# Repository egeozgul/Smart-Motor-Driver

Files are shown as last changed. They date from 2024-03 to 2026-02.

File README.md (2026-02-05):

# Servo Motor Feedback Controller

<p align="center">
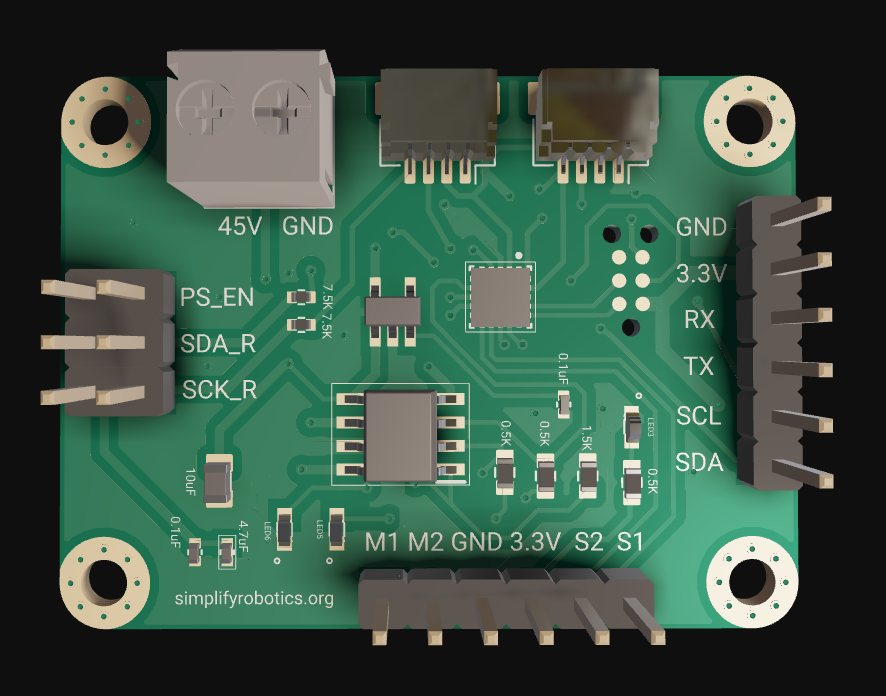
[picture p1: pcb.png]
Encoder Motor Driver - Front View
  
</p>

<!-- https://github.com/user-attachments/assets/069eb083-97e3-404b-9e9d-383a1cb0ce94 -->

## PCB assembly video
Watch the assembly video (https://youtu.be/LhhGqf6qH90)

The **Smart Encoder Motor Driver** is designed to control DC motors with magnetic or optical encoders. It features a built-in feedback controller and H-bridge, allowing precise motor power adjustment based on commands from a master device. Powered by the **STM32C0 microcontroller** and equipped with a **PID feedback system**, this driver ensures reliable and efficient motor control.

## Key Features
- **Built-in Feedback Controller**: High-frequency PID control for precise motor operation.
- **Trapezoidal Trajectory Planner**: Ensures smooth acceleration and deceleration by generating motion profiles for precise movement control.
- **Digital Communication**: Supports ASCII commands for setting motor target positions, tuning PID coefficients, monitoring torque feedback, and more.
- **Voltage Range**: 5V to 45V.
- **Current Capacity**: Up to 4.1 amps.
- **Communication**: Supports I2C and UART protocols.
- **Expandable Design**: Qwiic connectors allow daisy-chaining of up to 256 units on a single I2C port.

## Trapezoidal Trajectory Planner
The driver includes an **embedded trapezoidal trajectory generator**, which ensures smooth motor motion by controlling acceleration and deceleration. This feature prevents sudden jerks, reduces mechanical stress, and improves overall system stability.

### Key Benefits
- Smooth position transitions with controlled acceleration and deceleration.
- Prevents overshooting and oscillations.
- Customizable speed, acceleration, and deceleration limits.

### Motion Profile

The controller automatically computes the trajectory based on the target position, velocity, and acceleration constraints.
A custom web-based UART plotter is used for live plotting of motor motion parameters. 

The plots below display: 
1. Position
2. Velocity
3. Current drawn by the motor

scr

## Custom Live Plotter
A custom live plotter is built for monitoring the motor speed, acceleration, and current draw.  
Check out the [Live UART Plotter](https://egeozgul.github.io/live-uart/) to visualize real-time data from your motor driver.  
It supports plotting an unlimited number of variables with customizable styling.

## Final PCB Design Iteration
IMG-20250525-WA0009

447361824-5bac32cf-38b6-4dda-9f8f-5560bae4baff

The **PID feedback control system** ensures precise and stable motor control, making it suitable for robotics, automation, and other applications requiring high precision.

## Connectivity and Expansion
The motor driver is designed for scalability, using **Qwiic connectors** for easy daisy-chaining. This allows control of a large number of motors, making it ideal for projects requiring extensive motor coordination.

## License
This project is open-source under the MIT License. Feel free to modify and distribute it as needed!

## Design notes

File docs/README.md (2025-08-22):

# Smart Motor Driver Documentation

## Overview
The Smart Motor Driver is a high-precision motor control system based on STM32C0 microcontroller, featuring PID control, trapezoidal motion profiles, and multiple communication interfaces.

## Documentation Structure

### [User Guide](USER_GUIDE.md)
- Getting started guide
- Command interface tutorial
- Usage examples
- Troubleshooting guide
- No C code, focused on usage

### [Technical Reference](REFERENCE.md)
- Hardware specifications
- ASCII command protocol
- Motion control commands
- PID tuning parameters
- Motion profile settings
- Monitoring commands
- System commands

### [Source Code Documentation](SOURCECODE.md)
- Core components implementation
- Motion profile generation
- Communication interfaces
- Hardware interfaces
- Data structures
- C code explanations

## Quick Links

### Common Tasks
- [Basic Motor Control](USER_GUIDE.md#basic-motor-control)
- [PID Tuning Guide](USER_GUIDE.md#pid-tuning)
- [Command Reference](REFERENCE.md#ascii-command-protocol)
- [Implementation Details](SOURCECODE.md#core-components)

### Key Features
- Position and speed control
- Trapezoidal motion profiles
- PID control with anti-windup
- Current monitoring
- UART and I2C interfaces
- 64-bit position tracking

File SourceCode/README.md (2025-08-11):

# STM32 Motor Controller Firmware

## 1. Introduction

This document provides a comprehensive overview of the firmware for a sophisticated motor control system based on an STM32 microcontroller. The system is designed to offer precise control over a DC motor, featuring position and speed control, a command-line interface for configuration and monitoring, and support for both UART and I2C communication protocols.

The firmware is built upon the STM32 HAL library and integrates several peripherals, including timers for PWM signal generation and encoder reading, an ADC for current sensing, and DMA for efficient data handling.

### Key Features:

* **Dual Communication Interface:** Control and monitor the motor via both UART and I2C.
* **Advanced Motion Control:**
    * **PID Control:** A Proportional-Integral-Derivative (PID) controller for precise position holding.
    * **Trapezoidal Profiling:** Smooth acceleration and deceleration for point-to-point movements.
* **Real-time Monitoring:** Stream motor position, speed (in ticks per second), and current consumption.
* **Command-Line Interface (CLI):** An intuitive text-based command system to configure parameters and control the motor.
* **Quadrature Encoder Support:** High-resolution position feedback from the motor.
* **Current Sensing:** Onboard ADC for monitoring motor current draw.
* **DMA-driven Communication:** Efficient data transfer for both UART and I2C, minimizing CPU overhead.

## 2. Hardware Setup

The firmware is configured to work with a specific set of STM32 peripherals. The primary components are:

* **`TIM1`:** For PWM generation to drive the H-bridge.
* **`TIM3`:** For reading the quadrature encoder.
* **`ADC1`:** For current sensing.
* **`USART2`:** For UART communication (CLI).
* **`I2C1`:** For I2C slave communication.
* **`DMA`:** For handling `USART2` and `I2C1` data transfers.

## 3. Software Architecture

The firmware's architecture is event-driven and organized around a main processing loop. It initializes all peripherals, then enters an infinite loop to process incoming commands from UART or I2C, execute motor control logic (PID, Trapezoidal, etc.), and handle data logging. Interrupts are used for encoder counting and I2C communication.

## 4. Communication Protocol & API

The motor controller is operated by sending text-based commands terminated by a newline character (`\n`) over UART or I2C.

### General Commands

| Command | Argument | Description |
| :--- | :--- | :--- |
| `SETSPD` | `speed` (0-100) | Sets the motor speed (Note: This function appears to be a placeholder). |
| `SETPOS` | `position` (integer) | Sets the target position for the PID controller and enters `MOTOR_PID` mode. |
| `MOVETO` | `position` (integer) | Moves the motor to a target position using a trapezoidal profile. Enters `MOTOR_TRAPEZOID` mode. |
| `FLOAT` | None | Disengages the motor, allowing it to spin freely. |
| `BRAKE` | None | Brakes the motor by shorting the terminals through the H-bridge. |
| `GETSPD` | None | Returns the current speed of the motor in ticks per second. |
| `GETPOS` | None | Returns the current 64-bit encoder position. |
| `GET_ADC` | None | Returns the current motor current in milliamps (mA). |
| `STATUS` | None | Returns the current drive mode of the motor. |
| `RESET` | None | Resets the microcontroller. |

### Configuration Commands

| Command | Argument | Description |
| :--- | :--- | :--- |
| `SET_P` | `value` (float) | Sets the Proportional (Kp) gain for the PID controller. |
| `SET_I` | `value` (float) | Sets the Integral (Ki) gain for the PID controller. |
| `SET_D` | `value` (float) | Sets the Derivative (Kd) gain for the PID controller. |
| `GET_PID` | None | Returns the current Kp, Ki, and Kd values. |
| `SETMAX_VEL` | `value` (float) | Sets the maximum velocity for trapezoidal moves. |
| `SETMAX_ACC` | `value` (float) | Sets the maximum acceleration for trapezoidal moves. |
| `GETMAX_VEL` | None | Returns the current maximum velocity setting. |
| `GETMAX_ACC` | None | Returns the current maximum acceleration setting. |
| `LOG` | `period` (ms) | Starts streaming `pos`, `amps`, and `tps` data every `period` milliseconds. Set to 0 to disable. |
| `CONFIRM` | `0` or `1` | Disables (0) or enables (1) confirmation messages for set commands. |

### Example Usage (UART)

1.  **Set PID gains:**
    ```
    SET_P 0.005
    SET_I 0.0001
    SET_D 0.01
    ```

2.  **Move to position 50000:**
    ```
    MOVETO 50000
    ```

3.  **Start logging data every 100ms:**
    ```
    LOG 100
    ```

    *Output:*
    ```
    pos 12345,amps 150.5,tps 5000
    pos 17345,amps 152.3,tps 5000
    ...
    ```

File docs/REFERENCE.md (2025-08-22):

# Smart Motor Driver - Technical Reference

## Technical Specifications

### Hardware Configuration
* **Microcontroller**: STM32C0 series
* **PWM Frequency**: Timer1 based
* **Encoder Resolution**: Quadrature encoding (4x)
* **ADC Resolution**: 12-bit (0-4095 steps)
* **Communication**:
  - UART: DMA-based, configurable baud rate
  - I2C: Slave mode, 7-bit addressing

### Control Parameters
* **Position Range**: 64-bit signed (-2^63 to 2^63-1)
* **PID Update Rate**: ~1kHz
* **Current Sensing**:
  - Resolution: 0.8mA (3.3V/4095/1.5kΩ)
  - Range: 0-2.2mA

## ASCII Command Protocol

### Motion Control Commands

#### SETPOS
- **Format**: `SETPOS <position>`
- **Parameters**: 64-bit signed integer
- **Response**: "Pos <value>"
- **Description**: Sets target position in PID mode
- **Example**: `SETPOS 1000`
- **Behavior**:
  - Immediate position command
  - Uses current PID settings
  - No acceleration limiting

#### MOVETO
- **Format**: `MOVETO <position>`
- **Parameters**: 64-bit signed integer
- **Response**: "Moving to <value>"
- **Description**: Moves to position using trapezoidal profile
- **Example**: `MOVETO 5000`
- **Profile Types**:
  1. Triangular (short moves)
     - When distance < 2 * acceleration_distance
     - No constant velocity phase
  2. Trapezoidal (long moves)
     - Acceleration phase
     - Constant velocity phase
     - Deceleration phase
- **Timing**:
  - T_accel = V_max / A_max
  - T_const = (distance - 2*D_accel) / V_max

#### SETSPD
- **Format**: `SETSPD <speed>`
- **Parameters**: 0-100 (percentage)
- **Response**: "Speed <value>%"
- **Description**: Sets motor speed
- **Example**: `SETSPD 50`

### State Control Commands

#### FLOAT
- **Format**: `FLOAT`
- **Parameters**: None
- **Response**: None
- **Description**: Disables motor power
- **Effects**:
  - Sets both PWM channels to 0
  - Disables H-bridge outputs
  - Allows free shaft rotation
  - Minimal power consumption
- **Use Cases**:
  - Manual positioning
  - Emergency stop
  - Power saving mode
  - System initialization

#### BRAKE
- **Format**: `BRAKE`
- **Parameters**: None
- **Response**: None
- **Description**: Engages motor brake
- **Effects**:
  - Sets both PWM channels to 50%
  - Creates active braking torque
  - Holds position against external forces
  - Higher power consumption
- **Use Cases**:
  - Emergency stop
  - Position holding
  - Load testing
  - Safety lockout

### PID Control Commands

#### SET_P/SET_I/SET_D
- **Format**: `SET_P <value>`, `SET_I <value>`, `SET_D <value>`
- **Parameters**: Float value (scientific notation supported)
- **Response**: Confirms new value
- **Description**: Sets PID parameters
- **Examples**:
  ```
  SET_P 0.001   # Moderate response
  SET_P 0.0001  # Slower, smoother response
  SET_I 0.0001  # Light integral action
  SET_D 0.00001 # Light damping
  ```
- **Parameter Effects**:
  - P (Proportional):
    - Range: 0.0001 to 0.01
    - Controls position error response
    - Higher: Faster but may oscillate
    - Lower: Smoother but slower
  - I (Integral):
    - Range: 0.0 to 0.001
    - Eliminates steady-state error
    - Anti-windup limited to ±100
  - D (Derivative):
    - Range: 0.0 to 0.0001
    - Provides damping
    - Reduces overshoot

#### GET_PID
- **Format**: `GET_PID`
- **Response**: "Kp <p>,Ki <i>,Kd <d>"
- **Description**: Returns current PID values
- **Output Format**: Scientific notation, 7 decimal places
- **Default Values**:
  ```
  Kp = 0.0001
  Ki = 0.0
  Kd = 0.0
  ```

### Motion Profile Commands

#### SETMAX_VEL
- **Format**: `SETMAX_VEL <velocity>`
- **Parameters**: Float velocity value
- **Description**: Sets maximum velocity for profiles
- **Default**: 20.0

#### SETMAX_ACC
- **Format**: `SETMAX_ACC <acceleration>`
- **Parameters**: Float acceleration value (0.01-1.0)
- **Description**: Sets maximum acceleration for profiles
- **Default**: 0.05
- **Effects**:
  - Limits acceleration in trapezoidal profiles
  - Affects move time calculation
  - Influences jerk and smoothness
- **Calculation**:
  ```
  D_accel = (V_max * V_max) / (2 * A_max)
  T_accel = V_max / A_max
  ```

### Monitoring Commands

#### GETPOS
- **Format**: `GETPOS`
- **Response**: `Pos <value>`
- **Description**: Returns encoder position
- **Features**:
  - 64-bit signed integer
  - No overflow issues
  - Quadrature decoded (4x resolution)
  - Updates at ~1kHz

#### GETSPD
- **Format**: `GETSPD`
- **Response**: `Spd <value>`
- **Description**: Returns motor speed
- **Features**:
  - Units: counts/second
  - Filtered for noise reduction
  - Sign indicates direction
  - Updates at ~1kHz

#### GET_ADC
- **Format**: `GET_ADC`
- **Response**: `ADC <raw>,<mA>`
- **Description**: Returns current sensing data
- **Features**:
  - Raw ADC value (0-4095)
  - Calculated current in mA
  - 12-bit resolution
  - ~0.8mA per step

#### STATUS
- **Format**: `STATUS`
- **Response**: Current mode (FLOAT/BRAKE/PID/TRAPEZOID)
- **Description**: Returns drive state

### System Commands

#### LOG
- **Format**: `LOG <period>`
- **Parameters**: Integer period value
- **Description**: Sets data logging period

#### CONFIRM
- **Format**: `CONFIRM <0/1>`
- **Parameters**: 0 (off) or 1 (on)
- **Description**: Enables/disables command confirmations

## Features Reference

### Motion Profiles
- Trapezoidal velocity profile
- Automatic profile selection (triangular/trapezoidal)
- Configurable velocity and acceleration limits
- Real-time trajectory computation

### Position Control
- 64-bit position counter
- PID control with anti-windup
- Configurable gains
- Encoder-based feedback

### Current Monitoring
- ADC-based current sensing
- 12-bit resolution
- 1.5kΩ sense resistor
- Real-time measurement

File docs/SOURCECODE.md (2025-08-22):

# Smart Motor Driver - Source Code Documentation

## Core Components

### Motor Control System

#### PWM Control
* **Function**: `UpdatePWMDutyCycle(uint32_t channel, uint32_t value)`
* **Purpose**: Controls motor speed and direction using PWM channels
* **Implementation**:
  ```c
  // Configure PWM channel
  sConfigOC.OCMode = TIM_OCMODE_PWM1;
  sConfigOC.Pulse = value;          // PWM duty cycle
  sConfigOC.OCPolarity = TIM_OCPOLARITY_HIGH;
  // Start PWM output
  HAL_TIM_PWM_Start_optimized(&htim1, channel);
  ```
* **Usage**:
  - Channel 3: Forward direction
  - Channel 4: Reverse direction
  - Value range: 0 to Timer Period

#### Encoder Interface
* **Function**: `get_full_encoder_count()`
* **Purpose**: Reads absolute motor position
* **Implementation**:
  ```c
  int64_t count = full_encoder_count + 
                  __HAL_TIM_GET_COUNTER(&htim3) - 65536;
  ```
* **Features**:
  - 64-bit position counter
  - Overflow handling
  - High-resolution tracking

#### PID Controller
* **Function**: `update_PID()`
* **Purpose**: Closed-loop position control
* **Key Variables**:
  ```c
  float Kp = 0.0001;  // Proportional gain
  float Ki = 0.0;     // Integral gain
  float Kd = 0.0;     // Derivative gain
  #define INTEGRAL_MAX 100  // Anti-windup limit
  ```
* **Algorithm**:
  1. Position error calculation
  2. Integral accumulation with anti-windup
  3. Derivative computation
  4. PWM output generation

### Motion Profiles

#### Trapezoidal Profile Generator
* **Initialization**: `initializeTrajectory(int64_t start, int64_t target)`
* **Implementation**:
  ```c
  // Calculate acceleration distance
  D_accel = (V_max * V_max) / (2.0f * A_max);
  
  if (totalDistance < 2 * D_accel) {
      // Triangular profile
      D_accel = totalDistance / 2;
      T_accel = custom_sqrtf(2.0f * D_accel / A_max);
      T_const = 0.0f;
  } else {
      // Trapezoidal profile
      T_accel = V_max / A_max;
      T_const = (totalDistance - 2 * D_accel) / V_max;
  }
  ```
* **Profile Parameters**:
  - `V_max`: Maximum velocity (default: 20.0)
  - `A_max`: Maximum acceleration (default: 0.05)
  - `T_accel`: Acceleration/deceleration time
  - `T_const`: Constant velocity time

#### Profile Update
* **Function**: `updateTrajectory(float dt)`
* **Phases**:
  1. Acceleration: Quadratic position increase
  2. Constant velocity: Linear position change
  3. Deceleration: Inverted quadratic
* **Implementation**:
  ```c
  if (currentTime <= T_accel) {
      // Acceleration phase
      setpointPos = startPos + direction * 
          (int64_t)((A_max * currentTime * currentTime) / 2.0f);
  } else if (currentTime <= T_accel + T_const) {
      // Constant velocity phase
      setpointPos = startPos + direction * 
          (int64_t)(V_max * (currentTime - T_accel));
  }
  ```

### Communication Interfaces

#### UART Interface
* **Configuration**:
  ```c
  #define DMA_BUFFER_SIZE 2048
  uint8_t rxBuffer[DMA_BUFFER_SIZE];
  ```
* **Features**:
  - DMA circular buffer for efficient reception
  - Non-blocking command processing
  - Automatic buffer wraparound

* **Command Processing**:
  ```c
  void ProcessCommand(uint8_t *buffer, int bufferSize, 
                     DMA_HandleTypeDef *hdmarx, 
                     uint16_t *lastParsedIndex)
  ```

#### I2C Interface
* **Buffer Management**:
  ```c
  #define I2C_BUFFER_SIZE 64
  uint8_t i2cTxBuffer[I2C_BUFFER_SIZE];
  ```
* **Features**:
  - Slave mode with 7-bit addressing
  - Interrupt-driven data transmission
  - Cyclic buffer with overflow protection

* **Data Handling**:
  ```c
  void I2C_IRQHandler_User(I2C_HandleTypeDef *hi2c)
  ```

### Command Processing

#### Command Parser
* **Function**: `handleCommand(uint8_t *buffer, int bufferSize, uint16_t commandIndex)`
* **Buffer Processing**:
  ```c
  #define MAX_COMMAND_LENGTH 25
  char command[MAX_COMMAND_LENGTH];
  // Extract command from circular buffer
  for (int i = 0; i < MAX_COMMAND_LENGTH; i++) {
      int buffer_i = (commandIndex - i);
      if (buffer_i < 0)
          buffer_i = bufferSize - buffer_i;
      command[MAX_COMMAND_LENGTH - i - 1] = buffer[buffer_i];
  }
  ```

#### Command Parser Components
* **String Functions**:
  ```c
  int strcmp_embedded(const char *str1, const char *str2)
  int atoi_embedded(const char *str)
  ```
* **Command Format**: `COMMAND VALUE\n`
* **Error Handling**:
  - Buffer overflow protection
  - Invalid command detection
  - Value range validation

### Hardware Interfaces

#### ADC Interface
* **Function**: `readADCValue()`
* **Implementation**:
  ```c
  uint32_t readADCValue() {
      HAL_ADC_Start(&hadc1);
      if (HAL_ADC_PollForConversion(&hadc1, 100) == HAL_OK) {
          uint32_t adcValue = HAL_ADC_GetValue(&hadc1);
      }
      HAL_ADC_Stop(&hadc1);
      return adcValue;
  }
  ```
* **Current Calculation**:
  ```c
  float Vipropi = ((float)adc_value * (3.3f/4095.0f));
  float Ipropi = Vipropi/1.5f;  // Current in mA
  ```
* **Features**:
  - 12-bit resolution (0-4095)
  - Voltage reference: 3.3V
  - Current sense resistor: 1.5kΩ
  - Polling mode with timeout

#### Timer Configuration
* **PWM Timer (TIM1)**:
  - Channels 3,4: H-bridge control
  - Complementary outputs
  - Dead-time insertion

* **Encoder Timer (TIM3)**:
  - 16-bit counter
  - Quadrature decoding
  - Overflow handling for 64-bit position

### Key Data Structures
* **Cyclic Buffer**:
  ```c
  uint8_t i2cTxBuffer[I2C_BUFFER_SIZE];
  int head;  // Write position
  int tail;  // Read position
  int is_full;
  ```

### Important Constants
```c
#define DMA_BUFFER_SIZE 2048
#define I2C_BUFFER_SIZE 64
#define INTEGRAL_MAX 100
#define MAX_COMMAND_LENGTH 25
```

### Drive Modes
```c
#define MOTOR_FLOAT     0  // No power to motor
#define MOTOR_BRAKE     1  // Active braking
#define MOTOR_PID       2  // Position control
#define MOTOR_TRAPEZOID 3  // Profile motion
```

## Implementation Details

### PID Control Loop
```c
void update_PID() {
    int64_t currentPos = get_full_encoder_count();
    int64_t error = setpointPos - currentPos;
    integral += error;
    integral = constrain(integral, -INTEGRAL_MAX, INTEGRAL_MAX);
    int64_t derivative = error - previousError;
    double output = (Kp * error + Ki * integral + Kd * derivative)/10;
    // Apply output to PWM channels
}
```

### Trapezoidal Profile Generation
```c
void initializeTrajectory(int64_t start, int64_t target) {
    totalDistance = abs(target - start);
    D_accel = (V_max * V_max) / (2.0f * A_max);
    
    if (totalDistance < 2 * D_accel) {
        // Triangular profile
        D_accel = totalDistance / 2;
        T_accel = sqrt(2.0f * D_accel / A_max);
        T_const = 0;
    } else {
        // Trapezoidal profile
        T_accel = V_max / A_max;
        T_const = (totalDistance - 2 * D_accel) / V_max;
    }
}
```

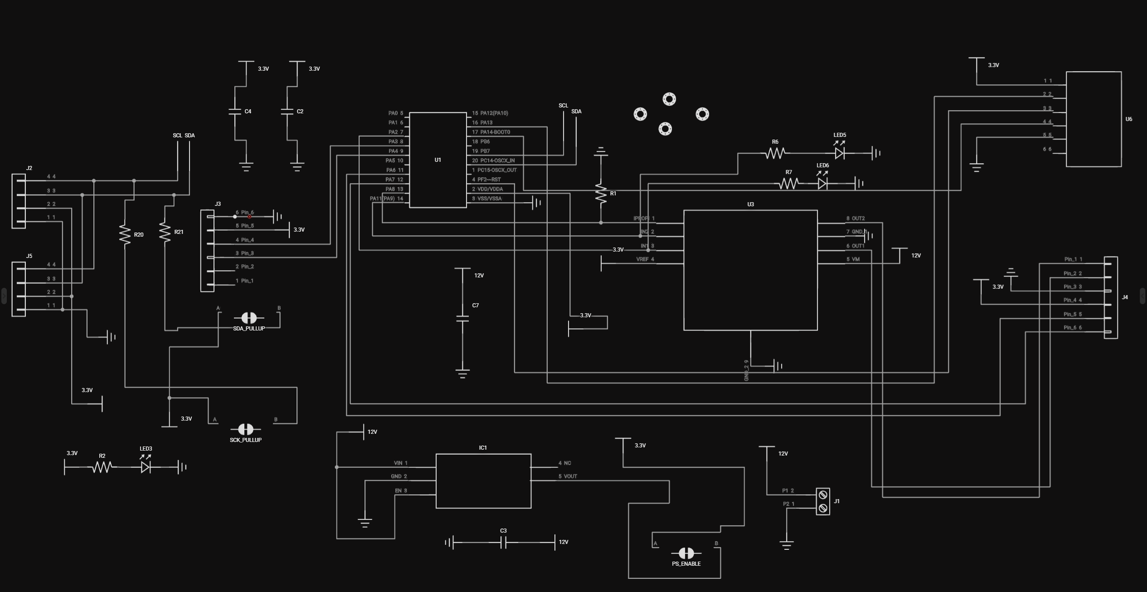
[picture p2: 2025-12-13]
schematic.png

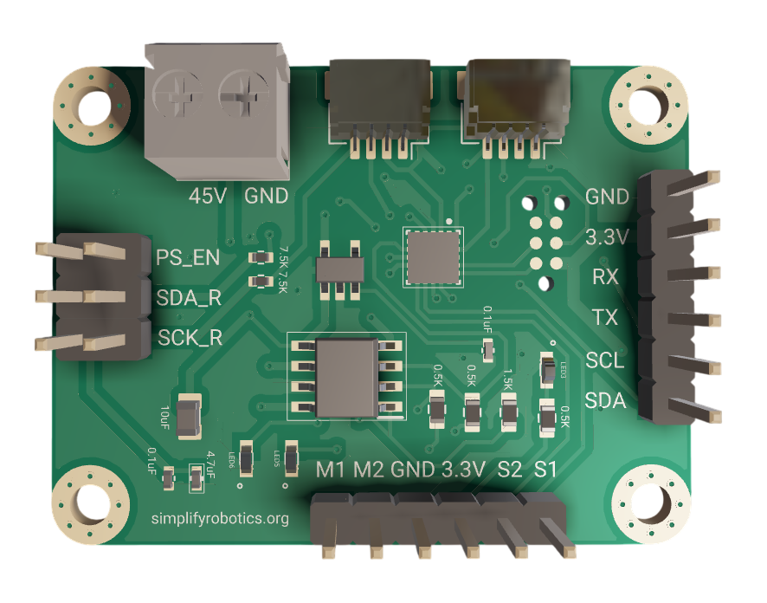
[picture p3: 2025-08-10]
pcb_transparent.png

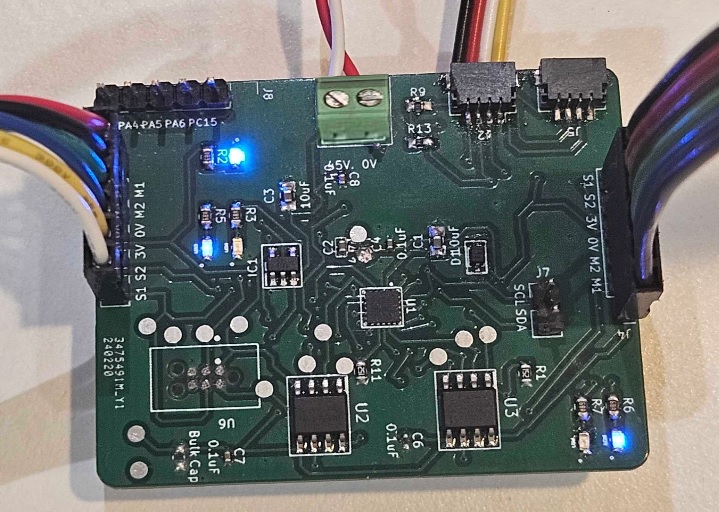
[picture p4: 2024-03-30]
imageC.jpg

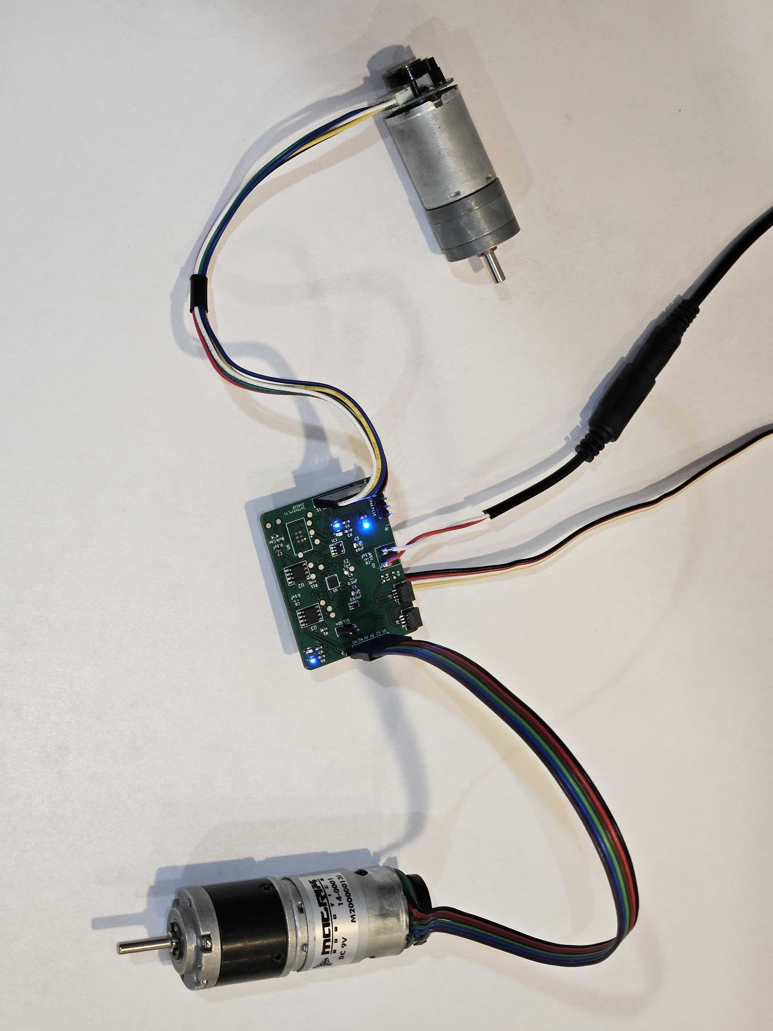
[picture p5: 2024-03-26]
imageA.jpg

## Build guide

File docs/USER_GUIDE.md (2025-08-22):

# Smart Motor Driver - User Guide

## Overview
The Smart Motor Driver is a sophisticated motor control system built on STM32 microcontroller, providing precise control over DC motor position, speed, and movement profiles. This guide explains how to use the system through its ASCII command interface over UART or I2C.

## Features
* High-precision position control with configurable PID parameters
* Variable speed control with PWM (0-100%)
* Advanced trapezoidal motion profiles for smooth movement
* Real-time current monitoring with mA resolution
* Multiple operation modes:
  - Float: No power to motor (free movement)
  - Brake: Active braking with 50% PWM
  - PID: Closed-loop position control
  - Trapezoid: Smooth motion with acceleration control

## Command Interface

### Basic Commands

#### Motor State Control
* `FLOAT` - Sets motor to floating state
  - Disables both PWM channels
  - Allows free movement of motor shaft
  - Useful for manual positioning or power saving

* `BRAKE` - Engages motor brake
  - Sets both PWM channels to 50% duty cycle
  - Creates active braking effect
  - Holds position against external forces

#### Status Commands
* `GETPOS` - Returns current motor position
  - Reports absolute encoder position
  - 64-bit counter value
  - Maintains position through power cycles

* `GETSPD` - Returns current motor speed
  - Reports real-time velocity
  - Calculated from encoder counts
  - Updates continuously

* `STATUS` - Shows current operating mode
  - Reports: FLOAT/BRAKE/PID/TRAPEZOID
  - Indicates active control method
  - Useful for debugging

### Motion Control

#### Position Commands
* `SETPOS <value>` - Set target position (PID mode)
  - Immediate position command
  - Uses PID control for positioning
  - Value is in encoder counts
  - Example: `SETPOS 1000`

* `MOVETO <value>` - Move to position using trapezoidal profile
  - Smooth motion with controlled acceleration
  - Automatically calculates optimal profile
  - Prevents mechanical stress
  - Example: `MOVETO 5000`

#### Speed Control
* `SETSPD <0-100>` - Set motor speed
  - Direct PWM duty cycle control
  - Range: 0% (stop) to 100% (full speed)
  - Linear speed control
  - Example: `SETSPD 75`

### PID Control

#### Tuning Commands
* `SET_P <value>` - Set proportional gain
  - Controls position error response
  - Higher values: faster response
  - Lower values: smoother motion
  - Example: `SET_P 0.001`

* `SET_I <value>` - Set integral gain
  - Eliminates steady-state error
  - Higher values: better position holding
  - Lower values: less oscillation
  - Example: `SET_I 0.0001`

* `SET_D <value>` - Set derivative gain
  - Dampens oscillations
  - Higher values: more damping
  - Lower values: faster response
  - Example: `SET_D 0.00001`

* `GET_PID` - Display current PID values
  - Shows all three parameters
  - Format: "Kp <p>,Ki <i>,Kd <d>"
  - Useful for tuning verification

### Motion Profile Settings

#### Velocity and Acceleration Control
* `SETMAX_VEL <value>` - Set maximum velocity
  - Limits peak velocity in trapezoidal profile
  - Units: encoder counts per second
  - Default: 20.0
  - Example: `SETMAX_VEL 15.5`

* `SETMAX_ACC <value>` - Set maximum acceleration
  - Controls acceleration/deceleration rate
  - Units: encoder counts per second²
  - Default: 0.05
  - Example: `SETMAX_ACC 0.03`

#### Profile Monitoring
* `GETMAX_VEL` - Display maximum velocity
  - Shows current velocity limit
  - Used for profile verification

* `GETMAX_ACC` - Display maximum acceleration
  - Shows current acceleration limit
  - Used for profile verification

### Monitoring and Diagnostics

#### Current Sensing
* `GET_ADC` - Read current sensor
  - Returns current in milliamps
  - High-precision ADC measurement
  - Resolution: 12-bit (4096 steps)
  - Range: 0 to (3.3V/1.5kΩ)

#### Data Logging
* `LOG <period>` - Set logging period
  - Sets update frequency for data output
  - Period in milliseconds
  - Example: `LOG 100` (10Hz update rate)

#### System Feedback
* `CONFIRM <0/1>` - Enable/disable command confirmations
  - 1: Enable command acknowledgments
  - 0: Disable command acknowledgments
  - Useful for debugging
  - Example: `CONFIRM 1`

## Usage Examples

1. Basic Position Control:
   ```
   SETPOS 1000    # Move to position 1000
   GETPOS         # Check current position
   ```

2. Smooth Motion Profile:
   ```
   SETMAX_VEL 20  # Set max velocity
   SETMAX_ACC 0.5 # Set max acceleration
   MOVETO 5000    # Move to position with trapezoidal profile
   ```

3. PID Tuning:
   ```
   SET_P 0.001    # Set proportional gain
   SET_I 0.0001   # Set integral gain
   SET_D 0.00001  # Set derivative gain
   GET_PID        # Verify settings
   ```

## Safety Features
* Current monitoring through ADC
* Software limits on velocity and acceleration
* Emergency stop through BRAKE command
* Motor float mode for manual positioning

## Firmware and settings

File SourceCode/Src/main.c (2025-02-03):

/*USER CODE BEGIN Header */
/**
 ******************************************************************************
 *@file           : main.c
 *@brief          : Main program body
 ******************************************************************************
 *@attention
 *
 *Copyright (c) 2024 STMicroelectronics.
 *All rights reserved.
 *
 *This software is licensed under terms that can be found in the LICENSE file
 *in the root directory of this software component.
 *If no LICENSE file comes with this software, it is provided AS-IS.
 *
 ******************************************************************************
 */

/*USER CODE END Header */
/*Includes ------------------------------------------------------------------*/
#include "main.h"
#include "helper.h"
//#include <stdarg.h>
//#include <stdio.h>
//#include <stdio.h>
//#include <string.h>
//#include <ctype.h>


//#include "stm32c0xx_ll_dma.h"
//#include "stm32c0xx_hal.h"
//#include "stm32c0xx_hal_uart.h"
//#include "stm32c0xx_hal_dma.h"

/*Private includes ----------------------------------------------------------*/
/*USER CODE BEGIN Includes */

/*USER CODE END Includes */

/*Private typedef -----------------------------------------------------------*/
/*USER CODE BEGIN PTD */

/*USER CODE END PTD */

/*Private define ------------------------------------------------------------*/
/*USER CODE BEGIN PD */

/*USER CODE END PD */

/*Private macro -------------------------------------------------------------*/
/*USER CODE BEGIN PM */

/*USER CODE END PM */

/*Private variables ---------------------------------------------------------*/
ADC_HandleTypeDef hadc1;
DMA_HandleTypeDef hdma_i2c1_rx;

I2C_HandleTypeDef hi2c1;

TIM_HandleTypeDef htim1;
TIM_HandleTypeDef htim3;

UART_HandleTypeDef huart2;
DMA_HandleTypeDef hdma_usart2_rx;
DMA_HandleTypeDef hdma_usart2_tx;

/*USER CODE BEGIN PV */
int computeEncoderCounterPeriod();

/*USER CODE END PV */

/*Private function prototypes -----------------------------------------------*/
void SystemClock_Config(void);
static void MX_GPIO_Init(void);
static void MX_DMA_Init(void);
static void MX_USART2_UART_Init(void);
static void MX_I2C1_Init(void);
static void MX_TIM1_Init(void);
static void MX_TIM3_Init(void);
static void MX_ADC1_Init(void);

/*USER CODE BEGIN PFP */
TIM_HandleTypeDef htim1;	// Assuming TIM1 is used



//#define strcmp_embedded strcmp
int strcmp_embedded(const char *str1, const char *str2) {
    // Compare characters until they differ or until we reach the end of either string
    while (*str1 && *str2 && *str1 == *str2) {
        str1++;
        str2++;
    }

    // Return the difference between the two differing characters
    return (unsigned char)(*str1) - (unsigned char)(*str2);
}

/*USER CODE END PFP */

/*Private user code ---------------------------------------------------------*/
/*USER CODE BEGIN 0 */


#define I2C_BUFFER_SIZE 64
uint8_t i2cRxBuffer[I2C_BUFFER_SIZE];
uint8_t i2cTxBuffer[I2C_BUFFER_SIZE]; // Sample response data



#define DMA_BUFFER_SIZE 2048
uint8_t rxBuffer[DMA_BUFFER_SIZE]  __attribute__((section(".bss")));	// Define the buffer to store received data
//uint8_t txBuffer[] = "Hello, DMA UART TX!";	// Define the buffer to be transmitted



//char i2cTxBuffer[BUFFER_SIZE];  // The buffer array
int head = 0;                   // Index for the next write position
int tail = 0;                   // Index for the next read position
int is_full = 0;           // Flag to indicate if the buffer is full

// Insert a character into the cyclic buffer
void buffer_insert(char c) {

	is_full = buffer_is_full();

    i2cTxBuffer[head] = c;  // Write the character at the head position
    head = (head + 1) % I2C_BUFFER_SIZE;  // Advance the head

    // If the buffer is full, advance the tail to overwrite the oldest character
    if (is_full == 1) {
        tail = (tail + 1) % I2C_BUFFER_SIZE;
    }

    // Set the full flag if the head meets the tail
    if(head == tail)
    	is_full = 1;
}

// Remove a character from the cyclic buffer
int buffer_remove(char *c) {
    if (head == tail && is_full == 0) {
        // Buffer is empty
        return 0;
    }

    *c = i2cTxBuffer[tail];  // Read the character at the tail position
    tail = (tail + 1) % I2C_BUFFER_SIZE;  // Advance the tail
    is_full = 0;  // Buffer is no longer full after removing an element
    return 1;
}

// Check if the buffer is empty
int buffer_is_empty() {
    return (head == tail && is_full == 0);
}

// Check if the buffer is full
int buffer_is_full() {
    return is_full;
}


/**
  * @brief  Transmit in slave mode an amount of data in non-blocking mode with Interrupt
  * @param  hi2c Pointer to a I2C_HandleTypeDef structure that contains
  *                the configuration information for the specified I2C.
  * @param  pData Pointer to data buffer
  * @param  Size Amount of data to be sent
  * @retval HAL status
  */


int dmaTransmissionComplete = 1;
void HAL_UART_TxCpltCallback(UART_HandleTypeDef *huart)
{
	if (huart->Instance == USART2)
	{
		dmaTransmissionComplete = 1;
		// Transmission complete callback
		// You can notify that the transmission is complete or take other actions
	}
}



/*
static void UART_SendString(char *string, int lenght)
{
	do {HAL_Delay(1);}
	while (dmaTransmissionComplete == 0);

	dmaTransmissionComplete = 0;
	if (HAL_UART_Transmit_DMA(&huart2, string, lenght) != HAL_OK)
	{
		dmaTransmissionComplete = 1;
		// Handle error
		Error_Handler();
	}

	//for interrupt uart
	//  HAL_UART_Transmit(&huart2, (uint8_t*) string, lenght, HAL_MAX_DELAY);
}
*/

//static void printBuffer(const char *string,uint16_t length)
//{
//        HAL_UART_Transmit(&huart2, (uint8_t *)string, length, HAL_MAX_DELAY);
//}

//static uint8_t index_b = 0; //index to read first
//uint32_t size_bb = 20; //size
//uint8_t i2cTxBuffer[I2C_BUFFER_SIZE] = "1234567890abcdefghijklmnoprstyx"; // Sample response data


#define I2C  1
#define UART 0
int peripheral = UART;

static void printString(const char *string)
{
	while (*string)
    {
		if(peripheral == UART)
			HAL_UART_Transmit(&huart2, (uint8_t *)string++, 1, HAL_MAX_DELAY);
		else if(peripheral == I2C)
			buffer_insert(string++);
    }
}


static void printBuffer(const uint8_t *pData, uint16_t Size)
{
	if(peripheral == UART)
	{
		HAL_UART_Transmit(&huart2, pData, Size, HAL_MAX_DELAY);
	}
	else if(peripheral == I2C)
	{
		for(int i=0;i<Size;i++)
		{
			buffer_insert((char)pData[i]);
		}
	}
}

static void printChar(char ch)
{

	if(peripheral == UART)
	{
	    HAL_UART_Transmit(&huart2, (uint8_t *)&ch, 1, HAL_MAX_DELAY);
	}
	else if(peripheral == I2C)
	{
		buffer_insert(ch);
	}
}

static void printUInt64(uint64_t value)
{
    char buffer[21];       // Buffer large enough for a 64-bit integer string with null terminator
    int index = 20;        // Start filling from the last position

    buffer[index] = '\0';  // Null terminator at the end of the buffer
    index--;

    // Convert the number to a string by extracting digits from the end
    do {
        buffer[index] = '0' + (value % 10);  // Get the last digit
        value /= 10;                         // Move to the next digit
        index--;                             // Move left in the buffer
    } while (value > 0);

    // Print the resulting string starting from the first non-empty position
    printString(&buffer[index + 1]);
}

static void printInt64(int64_t value)
{
    char buffer[21];       // Buffer large enough for a 64-bit integer string with null terminator
    int index = 20;        // Start filling from the last position
    int isNegative = value < 0;

    buffer[index] = '\0';  // Null terminator at the end of the buffer
    index--;

    // Special handling for INT64_MIN because it cannot be directly negated
    if (value == INT64_MIN) {
        value = INT64_MAX;     // Use INT64_MAX temporarily
        buffer[index] = '8';   // Manually set last digit for INT64_MIN
        index--;
    }
    else if (isNegative) {
        value = -value;        // Convert to positive if the value is negative
    }

    // Convert the number to a string by extracting digits from the end
    do {
        buffer[index] = '0' + (value % 10);  // Get the last digit
        value /= 10;                         // Move to the next digit
        index--;                             // Move left in the buffer
    } while (value > 0);

    // Add a negative sign if the original number was negative
    if (isNegative)
    {
        buffer[index] = '-';
        index--;
    }

    // Print the resulting string starting from the first non-empty position
    printString(&buffer[index + 1]);
}

static void printFloat(float value, int decimalPlaces)
{
    //char buffer[20];  // Buffer for the formatted string
    int integerPart = (int)value;
    float fractionalPart = value - (float)integerPart;

    if (value < 0)
    {
        //UART_SendChar('-');
        printChar('-');
        integerPart = -integerPart;
        fractionalPart = -fractionalPart;
    }

    // Send the integer part
    printInt64(integerPart);
    //UART_SendInt64(integerPart);

    // Send the decimal point
    //UART_SendChar('.');
    printChar('.');

    // Send the fractional part up to the specified decimal places
    for (int i = 0; i < decimalPlaces; i++)
    {
        fractionalPart *= 10;
        int digit = (int)fractionalPart;
        printChar('0' + digit);
        fractionalPart -= digit;
    }
}




static void UpdatePWMDutyCycle(uint32_t channel, uint32_t value)
{
	TIM_OC_InitTypeDef sConfigOC ;

	sConfigOC.OCMode = TIM_OCMODE_PWM1;
	sConfigOC.Pulse = value;
	sConfigOC.OCPolarity = TIM_OCPOLARITY_HIGH;
	sConfigOC.OCNPolarity = TIM_OCNPOLARITY_HIGH;
	sConfigOC.OCFastMode = TIM_OCFAST_DISABLE;
	sConfigOC.OCIdleState = TIM_OCIDLESTATE_RESET;
	sConfigOC.OCNIdleState = TIM_OCNIDLESTATE_RESET;
	HAL_TIM_PWM_ConfigChannel_optimized(&htim1, &sConfigOC, channel);
	HAL_TIM_PWM_Start_optimized(&htim1, channel);	// Start PWM
}



volatile int64_t full_encoder_count = 0;	// 32-bit counter
volatile uint32_t tim_counter = 0;

//DMA1_Channel1_IRQHandler
//void DMA1_Channel1_IRQHandler(void)
//{
//	UART_SendFormattedString("DMA1_Channel1_IRQHandler\n");
//
//    HAL_DMA_IRQHandler(&hdma_usart2_rx);
//}

//doesnt get fired
//void USART2_IRQHandler(void)
//{
//	UART_SendFormattedString("USART2_IRQHandler\n");
//}

volatile uint8_t halfBufferReceived = 0;
volatile uint8_t fullBufferReceived = 0;



void HAL_UART_RxCpltCallback(UART_HandleTypeDef *huart)
{
	//if (huart->Instance == USART2)
	//{

		//__HAL_UART_CLEAR_FLAG(&huart2, UART_FLAG_ORE | UART_FLAG_NE | UART_FLAG_FE | UART_FLAG_PE);
		//HAL_UART_DMAStop(&huart2);
		if (HAL_UART_Receive_DMA(&huart2, rxBuffer, DMA_BUFFER_SIZE) != HAL_OK)
		{
			//	UART_SendFormattedString("ERROR: Failed to restart DMA reception\n");
		}
//	}
}


#define ABS(number) (number < 0) ? -number : number;

//period of logging pos, amps, tps
uint32_t logPeriod = 0;
uint32_t confirm = 0;

// Define constraints
float V_max = 20.0f;    // Max velocity
float A_max = 0.05f;    // Max acceleration
float controlInterval = 0.01f; // Control interval in seconds (10 ms)

int64_t startPos, targetPos;
int64_t setpointPos;
int64_t totalDistance;
int64_t D_accel;
float T_accel, T_const, T_total;
int64_t direction = 1;
int8_t trapezoid = 0;


float currentTime = 0.0f;     // Current time in seconds


// Initialize trajectory parameters
void initializeTrajectory(int64_t start, int64_t target) {
    startPos = start;
    targetPos = target;
    setpointPos = startPos;
    totalDistance = targetPos - startPos;
    if(totalDistance<0)
    	totalDistance = -totalDistance;



    // Precompute parameters for acceleration
    D_accel = (int64_t)((V_max * V_max) / (2.0f * A_max));

    int64_t adjusted_D_accel = -1;

    if (totalDistance < 2 * D_accel) {
        // Triangular profile: max velocity is not reached
    	trapezoid = 0;
        adjusted_D_accel = totalDistance / 2;
        T_accel = custom_sqrtf(2.0f * adjusted_D_accel / A_max);
        D_accel = adjusted_D_accel;
        T_const = 0.0f; // No constant velocity phase
    } else {
        // Trapezoidal profile
    	trapezoid = 1;
        T_accel = V_max / A_max;
        T_const = (totalDistance - 2 * D_accel) / V_max;
    }

    // Total time for the trajectory
    T_total = 2.0f * T_accel + T_const;

    printFloat(T_accel,4);
        printChar(' ');
    printFloat(T_const,4);
    printChar(' ');
    printFloat(adjusted_D_accel,4);
    printChar(' ');

    currentTime = 0.0f;     // Current time in seconds

    direction = (targetPos - startPos)>0?(1):(-1);
}



int64_t get_full_encoder_count();

// Update trajectory
void updateTrajectory(float dt)
{
	currentTime += dt;

    if (currentTime <= T_accel) {
        // Acceleration phase
        setpointPos = startPos + direction*(int64_t)((A_max * currentTime * currentTime) / 2.0f);
    } else if (currentTime <= T_accel + T_const && trapezoid ==1) {
        // Constant velocity phase
        setpointPos = startPos + direction*D_accel + direction*(int64_t)(V_max * (currentTime - T_accel));
    }
    else if (currentTime <= T_total) {
        // Deceleration phase
        float t_decel = currentTime - (T_accel + T_const); // Time elapsed in deceleration phase

        // Ensure deceleration distance formula is consistent
        float d_decel = V_max * t_decel - 0.5f * A_max * t_decel * t_decel;

        // Compute position considering all phases
        setpointPos = (int64_t)(startPos
            + direction * D_accel
            + direction * (T_const * V_max)
            + direction * d_decel);
    }

    else {
        // Trajectory complete
        setpointPos = targetPos;
    }
}
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
int main(void)
{

	/*USER CODE BEGIN 1 */

	/*USER CODE END 1 */

	/*MCU Configuration--------------------------------------------------------*/

	/*Reset of all peripherals, Initializes the Flash interface and the Systick. */
	HAL_Init();

	/*USER CODE BEGIN Init */

	/*USER CODE END Init */

	/*Configure the system clock */
	SystemClock_Config();

	/*USER CODE BEGIN SysInit */

	/*USER CODE END SysInit */

	/*Initialize all configured peripherals */
	MX_GPIO_Init();
	MX_DMA_Init();
	MX_USART2_UART_Init();
	MX_I2C1_Init();
	//basicI2CInit();

	MX_TIM1_Init();
	MX_TIM3_Init();
	MX_ADC1_Init();

	//setupI2CReceive();


	/*USER CODE BEGIN 2 */
	//HAL_TIM_Encoder_Start(&htim3, TIM_CHANNEL_ALL);
	HAL_TIM_Encoder_Start_optimized_(&htim3);
	__enable_irq();
	/*USER CODE END 2 */

	/*HAL_StatusTypeDef uartResult = */HAL_UART_Receive_DMA(&huart2, rxBuffer, DMA_BUFFER_SIZE);

	/*if (uartResult == HAL_OK) {
	    	//printString("UART DMA receive setup successful.\n");
	    } else if (uartResult == HAL_ERROR) {
	    	//printString("UART DMA error: failed to initialize UART receive.\n");
	        // Additional error handling or retry logic can go here if needed
	    } else if (uartResult == HAL_BUSY) {
	    	//printString("UART DMA error: UART is busy.\n");
	        // Optionally add a retry mechanism if needed
	    } else if (uartResult == HAL_TIMEOUT) {
	    	//printString("UART DMA error: initialization timed out.\n");
	        // Handle timeout or retry as appropriate
	    }*/

	    HAL_Delay(1000);


	    HAL_I2C_DeInit(&hi2c1);  // Reset the I2C peripheral
	    HAL_Delay(100);

	    if (HAL_I2C_Init(&hi2c1) == HAL_OK) {
	        //printString("I2C reinitialized\n");
	    } //else {
	      //  printString("Failed to reinitialize I2C.\n");
	    //}

	    HAL_Delay(500);

	    while(hi2c1.State != HAL_I2C_STATE_READY)
	    {
		    //HAL_Delay(500);
		    //printString("I2C_STATE:");
		    //printUInt64(hi2c1.State);

	    }
	    //printString("HAL_I2C_STATE_READY");
	    HAL_Delay(500);


	    HAL_StatusTypeDef result = HAL_I2C_Slave_Receive_DMA(&hi2c1, i2cRxBuffer, I2C_BUFFER_SIZE);

	    //if (result == HAL_OK)
	    //{
	        //uint32_t error = HAL_I2C_GetError(&hi2c1);
	        //printString("HAL_OK.\n");
	    //}
	    //else if(result == HAL_BUSY)
	    //{
	        //printString("I2C HAL_BUSY.\n");
	    //}
	    //else
	    //{
	        //printString("I2C non-DMA receive setup success.\n");
	    //}
        //printString("I2C HAL Error Code.\n");

	    printUInt64(result);

	    HAL_Delay(100);

	    //__HAL_I2C_DISABLE_IT(&hi2c1, I2C_IT_ERRI | I2C_IT_TCI | I2C_IT_STOPI | I2C_IT_NACKI | I2C_IT_ADDRI | I2C_IT_RXI);
	    __HAL_I2C_DISABLE_IT(&hi2c1, I2C_IT_ERRI | I2C_IT_TCI | I2C_IT_NACKI | I2C_IT_RXI);
	    __HAL_I2C_DISABLE_IT(&hi2c1, I2C_IT_NACKI);

	    HAL_Delay(100);
	    __HAL_I2C_CLEAR_FLAG(&hi2c1, I2C_FLAG_AF);
		__HAL_I2C_CLEAR_FLAG(&hi2c1, I2C_FLAG_STOPF);
		__HAL_I2C_CLEAR_FLAG(&hi2c1, I2C_FLAG_OVR);
		__HAL_I2C_CLEAR_FLAG(&hi2c1, I2C_FLAG_BUSY);
		__HAL_I2C_CLEAR_FLAG(&hi2c1, I2C_FLAG_ALERT);

		__HAL_I2C_CLEAR_FLAG(&hi2c1, I2C_FLAG_AF | I2C_FLAG_STOPF | I2C_FLAG_OVR | I2C_FLAG_BERR);

		__HAL_I2C_ENABLE_IT(&hi2c1,I2C_IT_STOPI);
		__HAL_I2C_ENABLE_IT(&hi2c1,I2C_IT_ADDRI);
		__HAL_I2C_ENABLE_IT(&hi2c1,I2C_IT_TXI);



	    //printString("HAL_I2C_Interrupt_Enabled\n");

	/*Infinite loop */
	/*USER CODE BEGIN WHILE */
	//printString("READY\n");

	encoder_lastPos = get_full_encoder_count();
	encoder_lastTick = HAL_GetTick();
	adcReader_lastTick = HAL_GetTick();

	uint32_t frame_lastTick = HAL_GetTick();
	uint32_t frame_Tick = HAL_GetTick();

	while(1)
	{
		static uint16_t lastParsedIndex_uart = 0;	// Tracks the last parsed index in the DMA buffer
		ProcessCommand(rxBuffer, DMA_BUFFER_SIZE, (huart2.hdmarx), &lastParsedIndex_uart);


		static uint16_t lastParsedIndex_i2c = 0;	// Tracks the last parsed index in the DMA buffer
		ProcessCommand(i2cRxBuffer, I2C_BUFFER_SIZE, (hi2c1.hdmarx), &lastParsedIndex_i2c);
		__HAL_I2C_CLEAR_FLAG(&hi2c1, I2C_FLAG_AF | I2C_FLAG_STOPF | I2C_FLAG_OVR | I2C_FLAG_BUSY);




		encoder_currentPos = get_full_encoder_count();
		encoder_currentTick = HAL_GetTick();


		if(driveMode == MOTOR_TRAPEZOID)
		{

			frame_lastTick = frame_Tick;
			frame_Tick = HAL_GetTick();

			float dt = (frame_Tick - frame_lastTick)/1000.0f;

			updateTrajectory(dt);

			update_PID();
		}

		if(driveMode == MOTOR_PID)
		{
	        setpointPos = targetPos;
			update_PID();
		}



		if(logPeriod != 0)
		{
			if(logPeriod < 20)
			{
				logPeriod = 20;
			}

			static int64_t prev_encoderCount = 0;
			if(HAL_GetTick() - adcReader_lastTick > 80)
			{
				ADCbuffer_insert(readADCValue());
				adcReader_lastTick = HAL_GetTick();
			}

			if(HAL_GetTick() - encoder_lastTick > logPeriod)
			{
				int64_t encoder_currentPos = get_full_encoder_count();



				float filtered = filter_sma();
				printString("pos ");
				printInt64(encoder_currentPos);


				// VIPROPI (V) = IPROPI (A) x RIPROPI (1.5K Ω)
				//adc range: 0 - 4095

		//		printString("ADC:");
	//			uint32_t t = readADCValue();

				float Vipropi = (filtered*(3.3f/4095.0f));
				float Ipropi = Vipropi/1.5f;

				//printFloat(Ipropi,3);
				//printString(" mA\n");

				printString(",amps ");
				printFloat(Ipropi,3);


				//rpm computation:
				uint32_t deltaTick = HAL_GetTick() - encoder_lastTick;
				int64_t encoderCount = get_full_encoder_count();
				int64_t deltaCount = (int32_t)(encoderCount - prev_encoderCount);

				int64_t rpm = 0;
				if(deltaTick == 0)
				{
					rpm = 99999999;
				}
				else if(deltaTick > 1000)
				{
					rpm = 0;
				}
				else
				{
					rpm = deltaCount*1000/deltaTick;
				}

				prev_encoderCount = encoderCount;

				printString(",tps ");
				printInt64(rpm);
				printString("\n");

				//peripheral = I2C;
				//printBuffer("(GGGGG)",7);
				peripheral = UART;
				//HAL_UART_Transmit(&huart2, i2cTxBuffer, I2C_BUFFER_SIZE, HAL_MAX_DELAY);
				encoder_lastTick = HAL_GetTick();
			}

		}



	}

	/*USER CODE END WHILE */

	/*USER CODE BEGIN 3 */

	/*USER CODE END 3 */
}

/**
  * @brief ADC1 Initialization Function
  * @param None
  * @retval None
  */
static void MX_ADC1_Init(void)
{

  ADC_ChannelConfTypeDef sConfig;// = {0};

  /** Configure the global features of the ADC (Clock, Resolution, Data Alignment and number of conversion)
  */
  hadc1.Instance = ADC1;
  hadc1.Init.ClockPrescaler = ADC_CLOCK_SYNC_PCLK_DIV1;
  hadc1.Init.Resolution = ADC_RESOLUTION_12B;
  hadc1.Init.DataAlign = ADC_DATAALIGN_RIGHT;
  hadc1.Init.ScanConvMode = ADC_SCAN_DISABLE;
  hadc1.Init.EOCSelection = ADC_EOC_SINGLE_CONV;
  hadc1.Init.LowPowerAutoWait = DISABLE;
  hadc1.Init.LowPowerAutoPowerOff = DISABLE;
  hadc1.Init.ContinuousConvMode = DISABLE;
  hadc1.Init.NbrOfConversion = 1;
  hadc1.Init.DiscontinuousConvMode = DISABLE;
  hadc1.Init.ExternalTrigConv = ADC_SOFTWARE_START;
  hadc1.Init.ExternalTrigConvEdge = ADC_EXTERNALTRIGCONVEDGE_NONE;
  hadc1.Init.DMAContinuousRequests = DISABLE;
  hadc1.Init.Overrun = ADC_OVR_DATA_PRESERVED;
  hadc1.Init.SamplingTimeCommon1 = ADC_SAMPLETIME_1CYCLE_5;
  hadc1.Init.SamplingTimeCommon2 = ADC_SAMPLETIME_1CYCLE_5;
  hadc1.Init.OversamplingMode = DISABLE;
  hadc1.Init.TriggerFrequencyMode = ADC_TRIGGER_FREQ_HIGH;
  if (HAL_ADC_Init(&hadc1) != HAL_OK)
  {
    Error_Handler();
  }

  /** Configure Regular Channel
  */
  sConfig.Channel = ADC_CHANNEL_8;
  sConfig.Rank = ADC_REGULAR_RANK_1;
  sConfig.SamplingTime = ADC_SAMPLINGTIME_COMMON_1;
  if (HAL_ADC_ConfigChannel(&hadc1, &sConfig) != HAL_OK)
  {
    Error_Handler();
  }
}

//uint64_t full_encoder_count = 0;

void TIM3_IRQHandler(void)
{
	if (__HAL_TIM_GET_FLAG(&htim3, TIM_FLAG_UPDATE) != RESET)
	{
		if (__HAL_TIM_GET_IT_SOURCE(&htim3, TIM_IT_UPDATE) != RESET)
		{
			__HAL_TIM_CLEAR_IT(&htim3, TIM_IT_UPDATE);

			if (__HAL_TIM_IS_TIM_COUNTING_DOWN(&htim3))
			{
				full_encoder_count -= 0x10000;	// Decrement high-order counter on underflow
				//UART_SendFormattedString("underflow\n");
			}
			else
			{
				full_encoder_count += 0x10000;	// Increment high-order counter on overflow
				//UART_SendFormattedString("overflow\n");
			}
		}
	}
}
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

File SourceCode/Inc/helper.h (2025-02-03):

/*
 * helper.h
 *
 *  Created on: Nov 8, 2024
 *      Author: ege
 */

#ifndef INC_HELPER_H_
#define INC_HELPER_H_


float custom_sqrtf(float x) {
    if (x < 0.0f) {
        // Handle negative input gracefully (return 0 or NaN, depending on your use case)
        return 0.0f; // or NAN if <math.h> is included
    }
    if (x == 0.0f || x == 1.0f) {
        return x; // Handle edge cases directly
    }

    // Initial guess (you can fine-tune this for your range of inputs)
    float guess = x / 2.0f;

    // Newton-Raphson iterations
    for (int i = 0; i < 10; i++) { // 5 iterations are usually sufficient for good precision
        guess = 0.5f * (guess + x / guess);
    }

    return guess;
}


float ratof(char *arr)
{
  float val = 0;
  int afterdot=0;
  float scale=1;
  int neg = 0;

  if (*arr == '-') {
    arr++;
    neg = 1;
  }
  while (*arr) {
    if (afterdot) {
      scale = scale/10;
      val = val + (*arr-'0')*scale;
    } else {
      if (*arr == '.')
    afterdot++;
      else
    val = val * 10.0 + (*arr - '0');
    }
    arr++;
  }
  if(neg) return -val;
  else    return  val;
}

static int isdigit_(char ch)
{
    return (ch >= '0' && ch <= '9') || (ch == '.') || (ch == '-');
}

static int isalpha_(char ch)
{
    return ((ch >= 'A' && ch <= 'Z') || (ch >= 'a' && ch <= 'z'));
}

static void extractKeywordAndValue(const char *inputString, int length, char *keyword, char *value)
{
	int i = length - 1;
	int valueIndex = 0;
	int keywordIndex = 0;
	int hasFoundValue = 0;

	// Check the character before \n to determine if it is a letter or a number
	while (i >= 0 && (inputString[i] == '\n' || inputString[i] == ' '))
	{
		i--;
	}

	if (i >= 0 && isdigit_(inputString[i]))
	{
		// Found a numerical value, proceed to read the value
		while (i >= 0 && (inputString[i] != '\n' && inputString[i] != '\0' && inputString[i] != ' '))
		{
			if (isdigit_(inputString[i]))
			{
				value[valueIndex++] = inputString[i];
				hasFoundValue = 1;
			}

			i--;
		}

		// Null-terminate the value string and reverse it since it was read backwards
		if (hasFoundValue)
		{
			value[valueIndex] = '\0';
			for (int j = 0; j < valueIndex / 2; j++)
			{
				char temp = value[j];
				value[j] = value[valueIndex - j - 1];
				value[valueIndex - j - 1] = temp;
			}
		}

		// Check if a space character was found and proceed to find the keyword
		if (hasFoundValue && i >= 0 && inputString[i] == ' ')
		{
			i--;	// Move left to skip the space character
			// Traverse the string to find the keyword
			while (i >= 0 && (inputString[i] != '\n' && inputString[i] != '\0' && inputString[i] != ' '))
			{
				keyword[keywordIndex++] = inputString[i];
				i--;
			}

			// Null-terminate the keyword string and reverse it since it was read backwards
			if (keywordIndex > 0)
			{
				keyword[keywordIndex] = '\0';
				for (int j = 0; j < keywordIndex / 2; j++)
				{
					char temp = keyword[j];
					keyword[j] = keyword[keywordIndex - j - 1];
					keyword[keywordIndex - j - 1] = temp;
				}
			}
		}
	}
	else if (i >= 0 && isalpha_(inputString[i]))
	{
		// Found a single letter, proceed to read the keyword
		while (i >= 0 && (inputString[i] != '\n' && inputString[i] != '\0' && inputString[i] != ' '))
		{
			keyword[keywordIndex++] = inputString[i];
			i--;
		}

		// Null-terminate the keyword string and reverse it since it was read backwards
		if (keywordIndex > 0)
		{
			keyword[keywordIndex] = '\0';
			for (int j = 0; j < keywordIndex / 2; j++)
			{
				char temp = keyword[j];
				keyword[j] = keyword[keywordIndex - j - 1];
				keyword[keywordIndex - j - 1] = temp;
			}
		}
	}

}



/**
  * @brief  Starts the TIM Encoder Interface for both channels.
  * @param  htim TIM Encoder Interface handle
  * @retval HAL status
  */
static HAL_StatusTypeDef HAL_TIM_Encoder_Start_optimized_(TIM_HandleTypeDef *htim)
{
  HAL_TIM_ChannelStateTypeDef channel_1_state = TIM_CHANNEL_STATE_GET(htim, TIM_CHANNEL_1);
  HAL_TIM_ChannelStateTypeDef channel_2_state = TIM_CHANNEL_STATE_GET(htim, TIM_CHANNEL_2);
  HAL_TIM_ChannelStateTypeDef complementary_channel_1_state = TIM_CHANNEL_N_STATE_GET(htim, TIM_CHANNEL_1);
  HAL_TIM_ChannelStateTypeDef complementary_channel_2_state = TIM_CHANNEL_N_STATE_GET(htim, TIM_CHANNEL_2);

  /* Check the parameters */
  assert_param(IS_TIM_ENCODER_INTERFACE_INSTANCE(htim->Instance));

  /* Verify that all channels are ready */
  if ((channel_1_state != HAL_TIM_CHANNEL_STATE_READY) ||
      (channel_2_state != HAL_TIM_CHANNEL_STATE_READY) ||
      (complementary_channel_1_state != HAL_TIM_CHANNEL_STATE_READY) ||
      (complementary_channel_2_state != HAL_TIM_CHANNEL_STATE_READY))
  {
    return HAL_ERROR;
  }

  /* Set the channels to BUSY */
  TIM_CHANNEL_STATE_SET(htim, TIM_CHANNEL_1, HAL_TIM_CHANNEL_STATE_BUSY);
  TIM_CHANNEL_STATE_SET(htim, TIM_CHANNEL_2, HAL_TIM_CHANNEL_STATE_BUSY);
  TIM_CHANNEL_N_STATE_SET(htim, TIM_CHANNEL_1, HAL_TIM_CHANNEL_STATE_BUSY);
  TIM_CHANNEL_N_STATE_SET(htim, TIM_CHANNEL_2, HAL_TIM_CHANNEL_STATE_BUSY);

  /* Enable both channels */
  TIM_CCxChannelCmd(htim->Instance, TIM_CHANNEL_1, TIM_CCx_ENABLE);
  TIM_CCxChannelCmd(htim->Instance, TIM_CHANNEL_2, TIM_CCx_ENABLE);

  /* Enable the Peripheral */
  __HAL_TIM_ENABLE(htim);

  /* Return function status */
  return HAL_OK;
}
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

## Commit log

2025-08-10 Rename pcb (1)-Photoroom.png to pcb_transparent.png
2025-10-23 Rename mm (1).mp4 to assembly.mp4
